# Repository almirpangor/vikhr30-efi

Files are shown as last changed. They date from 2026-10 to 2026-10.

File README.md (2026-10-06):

# Вихрь-30 EFI

Блок управления впрыском и зажиганием для лодочного мотора «Вихрь-30» на STM32F103C6T6 (Blue Pill):
программа настройки, прошивка, схема и печатная плата.

| Папка | Что внутри |
|---|---|
| `app/` | Программа настройки 2.0 (TypeScript, React, свой WebGL-движок). `app/desktop/` — оболочка настольного приложения (Electron). Сборка: `node build.mjs`, тесты ядра: `npm test`. |
| `firmware/` | Прошивка v0.9 (исправленная) и v0.8 (для отката), симулятор и тесты на хосте, готовые HEX/BIN в `firmware/release/`. Читать `firmware/README_RU.md`. |
| `pcb/` | Печатная плата rev A: генератор, Gerber и сверловка в `pcb/out/`, файл KiCad, сборочные рисунки, перечень. Читать `pcb/out/README_RU.md`. |
| `release/` | Собранная программа одним HTML-файлом (Chrome/Edge). Установщик для Windows — в разделе Releases. |

## Состояние

Проверено без железа: 24 автотеста ядра программы, 48 проверок прошивки на симуляторе, соответствие Gerber схеме по всем 63 цепям.

**Не проверено на железе:** прошивка v0.9 на настоящем контроллере, программа с настоящим COM-портом,
установщик на Windows, плата (не изготавливалась, файл KiCad в KiCad не открывался), схема из новых деталей.
Перед заказом платы — список «Сверить перед заказом» в `pcb/out/README_RU.md`.

Первые включения — на стенде, с предохранителем и ограничением тока, без топлива. Цепи катушек — до 400 В.

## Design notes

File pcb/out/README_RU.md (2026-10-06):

# Плата блока управления «VIKHR-30 EFI rev A» (2026-10)

> **Состояние:** плата спроектирована программно по схеме из программы, проверена собственными скриптами (см. `CHECK.txt`), но **не изготавливалась и не испытывалась**. Файл KiCad в KiCad не открывался, штатный DRC KiCad не выполнялся. Часть посадочных мест нарисована по памяти — **перед заказом пройдите раздел «Сверить перед заказом»**.

## Параметры для заказа
| Параметр | Значение |
|---|---|
| Размер | 148 × 100 мм, прямоугольник |
| Слои | 2 (F.Cu, B.Cu), FR-4, толщина 1,6 мм |
| Медь | 35 мкм (1 oz) — минимум; **рекомендуется 70 мкм (2 oz)** для силовой части (шина +12V_F2, цепи катушек) |
| Мин. дорожка / зазор | 0,4 / 0,3 мм (фактический минимальный зазор 0,36 мм) |
| Мин. отверстие / площадка переходного | 0,4 / 0,8 мм (силовые 0,6 / 1,2) |
| Отверстия | металлизированных 326 (0,4…1,5 мм), неметаллизированных 6 (⌀3,2) |
| Маска | зелёная, с двух сторон; переходные закрыты маской |
| Шелкография | белая, с двух сторон (снизу — только название и «ДО 400 В») |
| Финиш | HASL (лучше бессвинцовый) |
| Контроль | электроконтроль (E-test) — заказать обязательно |

## Как заказать
- **Резонит** (rezonit.ru, «Срочные прототипы» / калькулятор): загрузить `vikhr30-efi-gerber.zip`; указать 2 слоя, 148 × 100, 1,6 мм, медь 35 или 70 мкм, маска зелёная, маркировка с двух сторон, HASL.
- **JLCPCB**: загрузить тот же zip; слои и размер определятся сами; Outer Copper Weight 1 oz или 2 oz; Surface Finish HASL. Плата больше 100 × 100 — цена выше минимальной.
- В архиве: `F_Cu`, `B_Cu`, `F_Mask`, `B_Mask`, `F_Paste`, `F_Silkscreen`, `B_Silkscreen`, `Edge_Cuts` (Gerber RS-274X, мм, 4.6) и сверловка `PTH.drl`, `NPTH.drl` (Excellon, мм, десятичные координаты). Начало координат — левый нижний угол платы.
- После загрузки **посмотрите предпросмотр завода**: должны быть видны сплошная заливка с обеих сторон, два «острова» под Q1/Q2 с широким зазором, 4 крепёжных отверстия по углам.

## Файлы
`vikhr30-efi.kicad_pcb` (+ `vikhr30-efi.kicad_dru` — правила зазоров, включая 2,5 мм для COIL1−/COIL2−), `top.svg/png`, `bottom.svg/png` (вид снизу — зеркально), `assembly.svg/png` (сборочный с номиналами), `all-layers.svg/png`, `bom.csv`, `placement.csv` (SMD), `pads.csv` (координаты всех выводов), `CHECK.txt` (результаты проверок), `../netlist.txt`, `../DECISIONS.md`.
В KiCad: зоны записаны уже залитыми — **не перезаливать (клавиша B)**, пока не подключён файл правил `.kicad_dru`, иначе KiCad зальёт с зазором 0,45 мм и возле ВВ-цепей. 3D-моделей в файле нет (в 3D будет видна только плата).

## Порядок сборки
1. Осмотреть плату, прозвонить: BAT+ ↔ GND, +12V_F2 ↔ GND, К1− ↔ GND, К2− ↔ GND — замыканий быть не должно.
2. **SMD**: D6…D9, D11 (BAR43S), Q3…Q6 (AO3400A), U3 (L293DD — ключ у вывода 1, точка на шелке), L1, D2 (SM8S30A: фланец-теплоотвод — АНОД, паяется на большую площадку в полигоне GND; отформованный вывод — катод, на малую площадку +12V_PROT у двойной черты на шелке) либо выводной P6KE33A/1.5KE33A в запасные отверстия, Q1, Q2 (D2PAK — фланец прогревать мощным паяльником или феном).
3. **Низкие выводные**: резисторы, диоды D3…D5 (полоска — к квадратной площадке), D1 (полоска вверх, к квадратной площадке).
4. Керамические конденсаторы, Q9 (BC547 — плоской стороной к клеммам, как на шелке), гнёзда PBS под A1 и A2, разъёмы JST.
5. Электролиты (плюс — квадратная площадка и знак «+»), Q7, Q8 (TO-220 стоя, фланец — к двойной линии на шелке), клеммники.
6. Модуль A5 — на двух стойках М3, четыре провода (или штыри) к площадкам IN+, IN−, OUT+, OUT−.
7. Промыть флюс. Силовую часть (вокруг Q1, Q2 и клемм катушек, **включая обратную сторону**) покрыть лаком для печатных плат.

## Проверка мультиметром ДО установки Blue Pill, HC-06 и подключения нагрузок
(цепи и ожидаемые значения — на вкладках «Схема» и «3D-схема» программы: щелчок по цепи показывает, что должно быть на ней)
1. Без питания: сопротивление BAT+ ↔ GND и +12V_F2 ↔ GND — не короткое; К1−, К2−, INJ, HTR, REL ↔ GND — не короткое (ключи закрыты).
2. Вставить предохранитель F1 (2 А), F2 пока **не ставить**. Подать 12 В от источника с ограничением тока 0,3…0,5 А.
3. +12V_PROT (катод D1, контакт IN+ модуля A5): на ~0,4 В меньше входного.
4. **Выставить подстроечником A5 ровно 5,00 В** на OUT+ (цепь +5V_ECU) — до установки A1!
5. +5V_SENS на контакте «5V» разъёмов TPS, MAP, CKP: 5,0 В. Контакт «5V» гнезда A1 (JR3): 5,0 В; контакты 3V3 пока пустые.
6. Затворы Q1, Q2 (IGN1_GATE, IGN2_GATE): около 0 В (катушки выключены, пока нет контроллера). Затворы Q7, Q8, база Q9: 0 В.
7. Обесточить, установить Blue Pill **по надписям контактов** (VBAT/3V3 — справа), включить: +3V3 = 3,3 В на R7, R10, R16, R18, R20, R38; PA4/PA5 без термисторов ≈ 3,3 В; PA6 ≈ U бортсети / 5,7.
8. Только после этого — F2, нагрузки по одной через тесты программы (вкладка «Тесты»), катушки — последними.

## Высокое напряжение — обязательно прочитать
- На клеммах **K1−, K2−**, фланцах Q1, Q2 и полигонах под ними **с обеих сторон платы** в момент искры до **400 В**. Не касаться при работающем двигателе; измерять только осциллографом со щупом 1:10 на 600 В.
- На плате зазор от этих цепей до любой другой меди ≥ 2,55 мм. **Внутри самих деталей он меньше**: у D2PAK между обрезанным средним выводом (коллектор) и выводами затвора/эмиттера около 1 мм по воздуху, между контактами клеммника 2,58 мм. Поэтому — лак, чистота, сухой корпус.
- Плату ставить на стойки не ниже 5 мм над металлом корпуса (снизу открытая медь ВВ-цепей под маской и выводы клемм). Рядом топливо: корпус блока — закрытый, вне зоны паров бензина.

## Сверить перед заказом (посадочные места по памяти и допущения)
| Что | Что сверить |
|---|---|
| D2 SM8S30A (DO-218AB) | **полярность**: по даташиту Vishay «Polarity: heatsink is anode» — на плате большая площадка = GND (анод), малая = +12V_PROT (катод); в rev A до рецензии было наоборот (исправлено). Сверить по даташиту купленного диода и прозвонить диод мультиметром до пайки. Размеры: площадки 10,5 × 9,3 и 3,0 × 3,8, зазор 2,45, длина 15,95; если не совпало — ставить выводной TVS в запасные отверстия (шаг 22,86, ⌀1,4; катод — квадратная площадка, полоска к ней) |
| Q1, Q2 IRGS14C40L (TO-263) | фланец 10,8 × 9,4; выводы 1,5 × 4,0, шаг 5,08; от центра фланца до центра площадок выводов 9,45; цоколёвка 1-G, 2-C (фланец), 3-E |
| L1 CDRH125 | площадки 3,0 × 5,4, между центрами 10,0 |
| U3 L293DD (SO-20W) | шаг 1,27, между рядами 9,3 — стандарт; убедиться, что куплен именно широкий SO-20 (7,5 мм) |
| A5 LM2596 | габарит ≤ 45 × 23, положение крепёжных отверстий (30,4 × 16,4 по диагонали) — у вашего модуля может отличаться |
| Клеммники 5,08 | глубина корпуса и положение выводов (на плате: 4,0 мм от ряда выводов внутрь платы, 4,6 мм к кромке); подписи контактов у самой кромки |
| A1 Blue Pill | расстояние между рядами 15,24; порядок выводов по надписям; с какого торца USB (см. `DECISIONS.md`, п. 11) |
| A2 HC-06 | порядок выводов STATE-RXD-TXD-GND-VCC-EN; у 4-контактных плат порядок другой — тогда проводами |
| BAR43S, AO3400A, BC547C, SS441A | цоколёвки (как в примечаниях схемы) |
| Q7, Q8 IRLZ44N | работа при 3,3 В на затворе (нагрев Q8 на токе нагревателя) |
| Q7, Q8 фланцы | фланец TO-220 — сток (цепи INJ−, HEATER−): радиаторы Q7 и Q8 раздельные или через изолирующие прокладки; общий радиатор и касание корпуса недопустимы |
| Переполюсовка аккумулятора | D1 защищает только ветвь F1. В ветви F2 при обратной полярности ток пойдёт через внутренние диоды Q7, Q8 и D3, D4 (1N4007) — диоды сгорят раньше, чем F2 10 А. Не путать полярность; это свойство схемы, платой не исправляется |
| Земля эмиттера Q2 | от эмиттера Q2 к клемме GND ток идёт через 3 переходных 1,2/0,6 на нижний полигон (у Q1 — ещё и дорожка 3 мм). Для импульсов 8 А достаточно, но при сборке можно пропаять эти переходные проволокой |
| USB-кабель Blue Pill | у «классической» Blue Pill USB со стороны контактов PB12/GND — т. е. слева, над D2 и в сторону модуля A5 (высота 14 мм, от торца Blue Pill ≈ 30 мм): штекер проходит выше D2, но длинный штекер может упереться в A5 |
| Перечень | клеммников нужно 8 × 2 конт. + 1 × 4 конт. (в перечне программы 6); гнездо PBS-1×6 под HC-06 |

## Токи (IPC-2221, подробно — раздел E в `CHECK.txt`)
Шина +12V_F2 и перемычка BAT+ (2,5 мм на двух слоях): 7,7 А при перегреве 10 °C и 10,4 А при 20 °C на меди 35 мкм; 17 А на 70 мкм. Средний ток нагрузок 3…5 А — запас есть, но номинал F2 (10 А) длительно плата с медью 35 мкм держит на пределе: **заказывайте 70 мкм** либо не превышайте 7 А длительно.

## Что не проверено
DRC KiCad; совпадение посадочных мест с реальными деталями; тепловой режим Q1, Q2 (оценка 1…2 Вт на корпус на максимальных оборотах — полигона 2 × 1,4 см² может не хватить, предусмотрите пластину-теплоотвод); помехоустойчивость аналоговых входов (трассировка автоматическая); сама схема на железе.

## Пересборка
`pcb/make.sh` — заново извлекает список цепей из схемы, разводит плату, выпускает все файлы и выполняет проверки.

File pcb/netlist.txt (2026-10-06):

СПИСОК ЦЕПЕЙ ПЛАТЫ «VIKHR-30 EFI rev A» — получен программно из листов схемы (pcb/netlist.ts)

Элементов на плате: 94; цепей: 63; выводов в цепях: 258

ЭЛЕМЕНТЫ НА ПЛАТЕ (обозначение | номинал | корпус | вывод=цепь)
A1    Blue Pill STM32F103C6T6      BLUEPILL_2x20    JL1=(NC) JL2=PC13 JL3=(NC) JL4=(NC) JL5=PA0 JL6=PA1 JL7=(NC) JL8=(NC) JL9=PA4 JL10=PA5 JL11=PA6 JL12=PA7 JL13=PB0 JL14=PB1 JL15=PB10 JL16=PB11 JL17=(NC) JL18=V33 JL19=GND JL20=GND JR1=V33 JR2=GND JR3=V5 JR4=PB9 JR5=PB8 JR6=PB7 JR7=PB6 JR8=PB5 JR9=(NC) JR10=(NC) JR11=(NC) JR12=(NC) JR13=(NC) JR14=PA10 JR15=PA9 JR16=PA8 JR17=PB15 JR18=PB14 JR19=PB13 JR20=PB12
A2    HC-06                        HDR_1x6          1=PB14 2=PA9_A2 3=PA10_A2 4=GND 5=V5 6=(NC)
A5    LM2596S, 5,00 В              LM2596_MODULE    1=V12 2=GND 3=V5 4=GND
C1    470 мкФ × 25 В               CP_D8_P3.5       1=V12 2=GND
C2    47 мкФ × 63 В                CP_D6.3_P2.5     1=V5S 2=GND
C3    0,1 мкФ                      C_DISC_5.08      1=PA0 2=GND
C4    0,1 мкФ                      C_DISC_5.08      1=PA1 2=GND
C5    0,1 мкФ                      C_DISC_5.08      1=PA4 2=GND
C6    0,1 мкФ                      C_DISC_5.08      1=PA5 2=GND
C7    0,1 мкФ                      C_DISC_5.08      1=PA6 2=GND
C8    0,1 мкФ                      C_DISC_5.08      1=PA7 2=GND
C9    0,1 мкФ                      C_DISC_5.08      1=V5 2=GND
C13   1 нФ                         C_DISC_5.08      1=PB5 2=GND
C14   1 нФ                         C_DISC_5.08      1=PB13 2=GND
C15   1 нФ                         C_DISC_5.08      1=PB12 2=GND
C16   47 мкФ × 63 В                CP_D6.3_P2.5     1=V5 2=GND
C17   47 мкФ × 63 В                CP_D6.3_P2.5     1=V12 2=GND
D1    SR560                        DO-201AD_15.24   1=V12 2=N_D1_A
D2    SM8S30A                      DO-218AB         1=V12 2=GND
D3    1N4007                       DO-41_10.16      1=F2 2=INJ
D4    1N4007                       DO-41_10.16      1=F2 2=HEAT
D5    1N4007                       DO-41_10.16      1=F2 2=RELAY
D6    BAR43S                       SOT-23           1=GND 2=V33 3=PA0
D7    BAR43S                       SOT-23           1=GND 2=V33 3=PA1
D8    BAR43S                       SOT-23           1=GND 2=V33 3=PA6
D9    BAR43S                       SOT-23           1=GND 2=V33 3=PA7
D11   BAR43S                       SOT-23           1=GND 2=V33 3=PB5
L1    47 мкГн                      CDRH125          1=V5 2=V5S
Q1    IRGS14C40L                   TO-263-2         1=G1 2=COIL1 3=GND
Q2    IRGS14C40L                   TO-263-2         1=G2 2=COIL2 3=GND
Q3    AO3400A                      SOT-23           1=N_Q3_1 2=GND 3=N_Q3_3
Q4    AO3400A                      SOT-23           1=N_Q3_3 2=GND 3=G1
Q5    AO3400A                      SOT-23           1=N_Q5_1 2=GND 3=N_Q5_3
Q6    AO3400A                      SOT-23           1=N_Q5_3 2=GND 3=G2
Q7    IRLZ44N                      TO-220_V         1=N_Q7_1 2=INJ 3=GND
Q8    IRLZ44N                      TO-220_V         1=N_Q8_1 2=HEAT 3=GND
Q9    BC547C                       TO-92            1=RELAY 2=N_Q9_2 3=GND
R1    10 кОм                       R_AXIAL_10.16    1=TPS_SIG 2=N_R1_2
R2    20 кОм                       R_AXIAL_10.16    1=N_R1_2 2=GND
R3    1 кОм                        R_AXIAL_10.16    1=N_R1_2 2=PA0
R4    10 кОм                       R_AXIAL_10.16    1=MAP_SIG 2=N_R4_2
R5    20 кОм                       R_AXIAL_10.16    1=N_R4_2 2=GND
R6    1 кОм                        R_AXIAL_10.16    1=N_R4_2 2=PA1
R7    2,4 кОм                      R_AXIAL_10.16    1=V33 2=N_R7_2
R8    91 Ом                        R_AXIAL_10.16    1=N_R7_2 2=PA4_X4
R9    1 кОм                        R_AXIAL_10.16    1=PA4_X4 2=PA4
R10   2,4 кОм                      R_AXIAL_10.16    1=V33 2=N_R10_2
R11   91 Ом                        R_AXIAL_10.16    1=N_R10_2 2=PA5_X5
R12   1 кОм                        R_AXIAL_10.16    1=PA5_X5 2=PA5
R13   47 кОм                       R_AXIAL_10.16    1=V12 2=PA6
R14   10 кОм                       R_AXIAL_10.16    1=PA6 2=GND
R15   10 кОм                       R_AXIAL_10.16    1=PA7_X6 2=PA7
R16   4,7 кОм                      R_AXIAL_10.16    1=V33 2=PB5_X7
R17   1 кОм                        R_AXIAL_10.16    1=PB5_X7 2=PB5
R18   10 кОм                       R_AXIAL_10.16    1=V33 2=PB13_X8
R19   1 кОм                        R_AXIAL_10.16    1=PB13_X8 2=PB13
R20   10 кОм                       R_AXIAL_10.16    1=V33 2=PB12_X9
R21   1 кОм                        R_AXIAL_10.16    1=PB12_X9 2=PB12
R22   1 кОм                        R_AXIAL_10.16    1=PA9 2=PA9_A2
R23   1 кОм                        R_AXIAL_10.16    1=PA10 2=PA10_A2
R24   330 Ом                       R_AXIAL_10.16    1=PB0 2=N_Q3_1
R25   10 кОм                       R_AXIAL_10.16    1=N_Q3_1 2=GND
R26   1 кОм                        R_AXIAL_10.16    1=V5 2=N_Q3_3
R27   470 Ом                       R_AXIAL_10.16    1=V5 2=G1
R28   330 Ом                       R_AXIAL_10.16    1=PB1 2=N_Q5_1
R29   10 кОм                       R_AXIAL_10.16    1=N_Q5_1 2=GND
R30   1 кОм                        R_AXIAL_10.16    1=V5 2=N_Q5_3
R31   470 Ом                       R_AXIAL_10.16    1=V5 2=G2
R32   100 Ом                       R_AXIAL_10.16    1=PB10 2=N_Q7_1
R33   100 кОм                      R_AXIAL_10.16    1=N_Q7_1 2=GND
R34   100 Ом                       R_AXIAL_10.16    1=PB15 2=N_Q8_1
R35   100 кОм                      R_AXIAL_10.16    1=N_Q8_1 2=GND
R36   1 кОм                        R_AXIAL_10.16    1=PB11 2=N_Q9_2
R37   10 кОм                       R_AXIAL_10.16    1=N_Q9_2 2=GND
R38   10 кОм                       R_AXIAL_10.16    1=V33 2=PC13
U3    L293DD                       SO-20W           1=PA8 2=PB6 3=IAC_A1 4=GND 5=GND 6=GND 7=GND 8=IAC_A2 9=PB7 10=V12 11=PA8 12=PB8 13=IAC_B1 14=GND 15=GND 16=GND 17=GND 18=IAC_B2 19=PB9 20=V5
X1    Клеммник 2 конт.             TERM_5.08_2      1=BAT 2=GND
X2    JST XH 3 конт.               JST_XH_3         1=V5S 2=TPS_SIG 3=GND
X3    JST XH 3 конт.               JST_XH_3         1=V5S 2=MAP_SIG 3=GND
X4    JST XH 2 конт.               JST_XH_2         1=PA4_X4 2=GND
X5    JST XH 2 конт.               JST_XH_2         1=PA5_X5 2=GND
X6    JST XH 2 конт.               JST_XH_2         1=PA7_X6 2=GND
X7    JST XH 3 конт.               JST_XH_3         1=V5S 2=PB5_X7 3=GND
X8    JST XH 2 конт.               JST_XH_2         1=PB13_X8 2=GND
X9    JST XH 2 конт.               JST_XH_2         1=PB12_X9 2=GND
X10   Клеммник 2 конт.             TERM_5.08_2      1=F2 2=COIL1
X11   Клеммник 2 конт.             TERM_5.08_2      1=F2 2=COIL2
X12   Клеммник 2 конт.             TERM_5.08_2      1=F2 2=INJ
X13   Клеммник 2 конт.             TERM_5.08_2      1=F2 2=RELAY
X14   Клеммник 2 конт.             TERM_5.08_2      1=F2 2=HEAT
X15   JST XH 4 конт.               TERM_5.08_4      1=IAC_A1 2=IAC_A2 3=IAC_B1 4=IAC_B2
X16   JST XH 4 конт. (USB-UART A3) JST_XH_4         1=GND 2=PA9 3=PA10 4=(NC)
XF1   Клеммник 2 конт. к держателю F1 (2 А) TERM_5.08_2      1=BAT 2=N_D1_A
XF2   Клеммник 2 конт. к держателю F2 (10 А) TERM_5.08_2      1=BAT 2=F2

ЦЕПИ (имя | название | выводы)
BAT          BAT+        X1.1 XF1.1 XF2.1
COIL1        COIL1−      Q1.2 X10.2
COIL2        COIL2−      Q2.2 X11.2
F2           +12V_F2     D3.1 D4.1 D5.1 X10.1 X11.1 X12.1 X13.1 X14.1 XF2.2
G1           IGN1_GATE   Q1.1 Q4.3 R27.2
G2           IGN2_GATE   Q2.1 Q6.3 R31.2
GND          GND         A1.JL19 A1.JL20 A1.JR2 A2.4 A5.2 A5.4 C1.2 C2.2 C3.2 C4.2 C5.2 C6.2 C7.2 C8.2 C9.2 C13.2 C14.2 C15.2 C16.2 C17.2 D2.2 D6.1 D7.1 D8.1 D9.1 D11.1 Q1.3 Q2.3 Q3.2 Q4.2 Q5.2 Q6.2 Q7.3 Q8.3 Q9.3 R2.2 R5.2 R14.2 R25.2 R29.2 R33.2 R35.2 R37.2 U3.4 U3.5 U3.6 U3.7 U3.14 U3.15 U3.16 U3.17 X1.2 X2.3 X3.3 X4.2 X5.2 X6.2 X7.3 X8.2 X9.2 X16.1
HEAT         HEATER−     D4.2 Q8.2 X14.2
IAC_A1       IAC_A1      U3.3 X15.1
IAC_A2       IAC_A2      U3.8 X15.2
IAC_B1       IAC_B1      U3.13 X15.3
IAC_B2       IAC_B2      U3.18 X15.4
INJ          INJ−        D3.2 Q7.2 X12.2
MAP_SIG      MAP         R4.1 X3.2
N_D1_A       N_D1_A      D1.2 XF1.2
N_Q3_1       N_Q3_1      Q3.1 R24.2 R25.1
N_Q3_3       N_Q3_3      Q3.3 Q4.1 R26.2
N_Q5_1       N_Q5_1      Q5.1 R28.2 R29.1
N_Q5_3       N_Q5_3      Q5.3 Q6.1 R30.2
N_Q7_1       N_Q7_1      Q7.1 R32.2 R33.1
N_Q8_1       N_Q8_1      Q8.1 R34.2 R35.1
N_Q9_2       N_Q9_2      Q9.2 R36.2 R37.1
N_R1_2       N_R1_2      R1.2 R2.1 R3.1
N_R4_2       N_R4_2      R4.2 R5.1 R6.1
N_R7_2       N_R7_2      R7.2 R8.1
N_R10_2      N_R10_2     R10.2 R11.1
PA0          PA0         A1.JL5 C3.1 D6.3 R3.2
PA1          PA1         A1.JL6 C4.1 D7.3 R6.2
PA4          PA4         A1.JL9 C5.1 R9.2
PA4_X4       PA4_X4      R8.2 R9.1 X4.1
PA5          PA5         A1.JL10 C6.1 R12.2
PA5_X5       PA5_X5      R11.2 R12.1 X5.1
PA6          PA6         A1.JL11 C7.1 D8.3 R13.2 R14.1
PA7          PA7         A1.JL12 C8.1 D9.3 R15.2
PA7_X6       PA7_X6      R15.1 X6.1
PA8          PA8         A1.JR16 U3.1 U3.11
PA9          PA9         A1.JR15 R22.1 X16.2
PA9_A2       PA9_A2      A2.2 R22.2
PA10         PA10        A1.JR14 R23.1 X16.3
PA10_A2      PA10_A2     A2.3 R23.2
PB0          PB0         A1.JL13 R24.1
PB1          PB1         A1.JL14 R28.1
PB5          PB5         A1.JR8 C13.1 D11.3 R17.2
PB5_X7       PB5_X7      R16.2 R17.1 X7.2
PB6          PB6         A1.JR7 U3.2
PB7          PB7         A1.JR6 U3.9
PB8          PB8         A1.JR5 U3.12
PB9          PB9         A1.JR4 U3.19
PB10         PB10        A1.JL15 R32.1
PB11         PB11        A1.JL16 R36.1
PB12         PB12        A1.JR20 C15.1 R21.2
PB12_X9      PB12_X9     R20.2 R21.1 X9.1
PB13         PB13        A1.JR19 C14.1 R19.2
PB13_X8      PB13_X8     R18.2 R19.1 X8.1
PB14         PB14        A1.JR18 A2.1
PB15         PB15        A1.JR17 R34.1
PC13         PC13        A1.JL2 R38.2
RELAY        RELAY−      D5.2 Q9.1 X13.2
TPS_SIG      TPS         R1.1 X2.2
V5           +5V_ECU     A1.JR3 A2.5 A5.3 C9.1 C16.1 L1.1 R26.1 R27.1 R30.1 R31.1 U3.20
V5S          +5V_SENS    C2.1 L1.2 X2.1 X3.1 X7.1
V12          +12V_PROT   A5.1 C1.1 C17.1 D1.1 D2.1 R13.1 U3.10
V33          +3V3        A1.JL18 A1.JR1 D6.2 D7.2 D8.2 D9.2 D11.2 R7.1 R10.1 R16.1 R18.1 R20.1 R38.1

ВНЕ ПЛАТЫ (подключаются через разъёмы)
GB1   12 В                           1=BAT 2=GND
F1    2 А                            1=BAT 2=N_D1_A
F2    10 А                           1=BAT 2=F2
A3    USB-UART PL2303HX              GND=GND TXD=PA10 RXD=PA9 +5V=(NC) 3V3=(NC)
A4    ST-Link V2                     GND=GND SWDIO=SWDIO SWCLK=SWCLK 3.3V=(NC)
RP1   Датчик дросселя                1=V5S 2=GND 3=TPS_SIG
B2    MPX4115AP                      2:GND=GND 3:Vs=V5S 1:Вых.=MAP_SIG
RT1   NTC 10 кОм B3950               1=PA4_X4 2=GND
RT2   NTC 10 кОм B3950               1=PA5_X5 2=GND
B3    Лямбда-зонд                    1/Масса=GND 2/1=F2 1/Сигн.=PA7_X6 2/2=HEAT
B1    SS441A                         2:GND=GND 1:+=V5S 3:Вых.=PB5_X7
S1    Перемычка SERVICE              1=PB13_X8 2=GND
S2    Чека STOP                      1=PB12_X9 2=GND
M1    Бензонасос                     1=N_K1_1_2 2=GND
T1    Катушка зажигания 1            1=F2 2=COIL1
T2    Катушка зажигания 2            1=F2 2=COIL2
Y1    Форсунка Bosch 0 280 158 117   1=F2 2=INJ
K1    Реле 12 В 30 А                 1=F2 2=RELAY 1/1=F2 1/2=N_K1_1_2
M2    Шаговый РХХ                    1/1=IAC_A1 1/2=IAC_A2 2/1=IAC_B1 2/2=IAC_B2

ПРЕОБРАЗОВАНИЯ «СХЕМА → ПЛАТА»
 - F1: держатель ножевого предохранителя вне платы; на плате клеммник XF1: 1 → BAT, 2 → N_D1_A.
 - F2: держатель ножевого предохранителя вне платы; на плате клеммник XF2: 1 → BAT, 2 → F2.
 - A3 (USB-UART) на плату не ставится: разъём X16 JST XH 4 конт.: 1 GND, 2 → RXD адаптера (PA9), 3 ← TXD адаптера (PA10), 4 не подключён (3V3 адаптера).
 - A2 (HC-06): гнездо 1×6, порядок как на модуле: 1 STATE, 2 RXD, 3 TXD, 4 GND, 5 VCC, 6 EN (не подключён).
 - A1: контакты SWD (S1…S4) находятся на торце самой Blue Pill и на плату не выводятся; A4 (ST-Link) подключается прямо к ним. Цепи SWDIO/SWCLK на плате отсутствуют.

ЗАМЕЧАНИЯ ПРИ ИЗВЛЕЧЕНИИ
 - Участок с цветом цепи «PA9» без метки на листе mcu (A2.RXD, R22.2) — отдельная цепь PA9_A2
 - Участок с цветом цепи «PA10» без метки на листе mcu (A2.TXD, R23.2) — отдельная цепь PA10_A2
 - Участок с цветом цепи «PA4» без метки на листе sensors (X4.1:Сигн., RT1.1, R8.2, R9.1) — отдельная цепь PA4_X4
 - Участок с цветом цепи «PA5» без метки на листе sensors (X5.1:Сигн., RT2.1, R11.2, R12.1) — отдельная цепь PA5_X5
 - Участок с цветом цепи «PA7» без метки на листе sensors (B3.1.Сигн., X6.1:Сигн., R15.1) — отдельная цепь PA7_X6
 - Участок с цветом цепи «PB5» без метки на листе sensors (B1.3:Вых., X7.2:Вых., R16.2, R17.1) — отдельная цепь PB5_X7
 - Участок с цветом цепи «PB13» без метки на листе sensors (X8.1:Вход, S1.1, R18.2, R19.1) — отдельная цепь PB13_X8
 - Участок с цветом цепи «PB12» без метки на листе sensors (X9.1:Вход, S2.1, R20.2, R21.1) — отдельная цепь PB12_X9
 - Участок с цветом цепи «IAC_OUT» без метки на листе iac (U3.3:OUT1, X15.1:A1, M2.1.1) — отдельная цепь IAC_A1
 - Участок с цветом цепи «IAC_OUT» без метки на листе iac (U3.8:OUT2, X15.2:A2, M2.1.2) — отдельная цепь IAC_A2
 - Участок с цветом цепи «IAC_OUT» без метки на листе iac (U3.13:OUT3, X15.3:B1, M2.2.1) — отдельная цепь IAC_B1
 - Участок с цветом цепи «IAC_OUT» без метки на листе iac (U3.18:OUT4, X15.4:B2, M2.2.2) — отдельная цепь IAC_B2

ПРОВЕРКА
 Замечаний нет: каждый вывод каждого элемента на плате имеет цепь или явно свободен; цепей с одним выводом нет; все элементы SCHEME_PARTS найдены.

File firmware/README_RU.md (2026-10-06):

# Прошивка блока впрыска «Вихрь-30», версия 0.9.0-C6-BT-DIAG

STM32F103C6T6A, bare-metal C, без HAL и библиотек. Это исправленная v0.8:
протокол и страница калибровок те же, программа настройки работает без
переделки.

## ВАЖНО: чего эта прошивка НЕ прошла

**Образ v0.9 ни разу не запускался на настоящем контроллере — ни автором
исправлений, ни кем-либо ещё.** Он собран clang 18 + ld.lld (v0.8 собиралась
arm-none-eabi-gcc). Проверено всё, что можно проверить без железа: логика —
на симуляторе на ПК (48 проверок, см. `tests/RESULTS.txt`), образ —
статически (векторы, размеры, HEX = BIN, дизассемблер). Первое включение —
только на стенде без катушек, форсунки и насоса, по порядку из раздела
«Первая проверка».

## Что было неверно в v0.8 и что сделано

Номера строк: «v0.8» — `tests/v0.8/main.c`, «v0.9» — `src/main.c`.

### 1. Таймер TIM2 — 16-разрядный, а код считал его 32-разрядным (критично)

v0.8, строка 1091: `TIM2->ARR=0xFFFFFFFF`. В STM32F103 счётчик TIM2 считает
только до 65535, то есть при шаге 1 мкс обнуляется каждые 65,5 мс. Отсюда:

- событие «выключить катушку/форсунку», назначенное на время после
  обнуления, никогда не выполнялось: проверка в строке 676 сравнивала
  число больше 65535 со счётчиком, который до него не доходит. Запись
  оставалась в очереди навсегда, очередь из 12 мест забивалась;
- зуб, пришедший сразу после обнуления, отбрасывался (строка 725), счёт
  зубьев сбивался;
- проверка «двигатель остановился» (строка 1121) срабатывала ложно почти
  после каждого обнуления, а настоящую остановку на 250 мс измерить не могла.

На симуляторе v0.8 при 3000 об/мин за 3,2 с: из 320 искр выдано 57, из 320
впрысков 187, катушка оставалась под током до 14,7 мс (норма 1,6 мс),
форсунка открыта до 12,5 мс (норма 2,1 мс). При 300–600 об/мин искр не было
вообще.

Сделано в v0.9:

- `micros()` (строка 736): 32-разрядное время в микросекундах. Старшую часть
  считает прерывание переполнения TIM2 (строка 810). Чтение защищено от
  гонки: если переполнение уже случилось, но ещё не посчитано, это видно по
  флагу UIF;
- новый планировщик (строки 744–816): на каждое действие своя ячейка
  (включить/выключить катушку 1 и 2, закрыть форсунку), время хранится в
  32 битах. Событие в прошлом выполняется сразу, далёкое — через
  промежуточные пробуждения. Очередь не может переполниться;
- включение выхода и назначение его выключения делаются в одном прерывании,
  поэтому катушка и форсунка выключаются таймером, даже если основной цикл
  занят или двигатель внезапно встал.

### 2. Обнаружение остановки читало время раньше, чем метку зуба

v0.8, строки 1117 и 1120: время бралось в начале цикла, метка последнего зуба
— позже. Если между ними приходил зуб, разность получалась «отрицательной»
(огромной), и блок решал, что двигатель стоит: сбрасывал синхронизацию и
выключал выходы. Контрольный опыт на симуляторе показал, что из-за этого
v0.8 не работала бы даже с 32-разрядным таймером (12 искр из 320).
Побочное следствие: блокировка SERVICE/обороты пропускала команды `SET`,
`SAVE`, `TEST` на вращающемся двигателе.

v0.9, строки 1331–1344: время, метка и сброс состояния — в одной защищённой
секции.

### 3. Период зуба после сбоя или помехи

- v0.8 не сбрасывала измеренный период зуба при остановке. После обрыва
  сигнала на 3000 об/мин и повторной прокрутки каждый зуб принимался за
  пропуск венца: на симуляторе 348 искр вместо 30 за 3 с, катушка под током
  до 18 мс.
- Два импульса помехи перед началом прокрутки давали то же самое, причём
  навсегда: блок показывал 12000 об/мин и отсекал зажигание и топливо.

v0.9: период сбрасывается при остановке (строка 1340) и при паузе больше
100 мс (строка 889); «пропуск» сразу после пропуска считается ошибкой
измерения, период измеряется заново (строка 899).

- Целочисленный фильтр периода в v0.8 (строка 731) после торможения
  застревал до 7 мкс ниже истинного значения: при 6000 об/мин это 2,5 % и
  искра примерно на 3,6° раньше заданной. В v0.9 фильтр считает в 1/8 мкс
  (строка 910), ошибка не больше 0,5 мкс.

### 4. Передача по UART останавливала основной цикл

v0.8 ждала отправки каждого байта (строки 382–386). Телеметрия в два порта
занимала 18–20 мс десять раз в секунду, ответ `GET MAPS` — 115 мс.
Что показал симулятор:

- залп из 234 команд `SET` при простое v0.8 **выдерживает** (все 234
  применены): за 18 мс приходит около 212 байт, буфер 256. Запас 43 байта;
- если залп идёт сразу после `GET MAPS`, v0.8 теряет 64 команды из 234;
- несколько длинных запросов подряд останавливали цикл v0.8 на 770 мс при
  сторожевом таймере 1 с.

v0.9: передача по прерыванию через кольцевые буферы 2048 байт на порт
(строки 422–471), приём 512 байт. Телеметрия отправляется только если строка
помещается целиком (строка 1358), иначе пропускается. Ответы на команды не
теряются: если буфер полон, блок ждёт освобождения места. За один проход
цикла выполняется одна команда (строка 1265). Результат: все 234 команды
применены в обоих случаях, цикл не задерживается дольше 1,5 мс; при четырёх
`GET MAPS` подряд — до 106 мс.

### 5. Прочее

- **Запись Flash и тестовый импульс.** `TEST INJECTOR` и сразу `SAVE` в v0.8
  держали форсунку открытой 68,5 мс: запись Flash запрещает прерывания
  примерно на 43 мс. v0.9 перед записью обрывает тест (строки 1242–1246).
- **Таймауты ожидания** в v0.8 никогда не срабатывали (проверялся счётчик
  после переполнения): при неисправном PLL, АЦП или Flash блок считал, что
  всё в порядке. v0.9: макрос `WAIT_WHILE` (строка 43).
- **Сторожевой таймер.** v0.8 записывала делитель до запуска IWDG. По
  документации (RM0008) значения переносятся только при работающем LSI,
  а он включается запуском; v0.8 работала за счёт несработавшего таймаута.
  v0.9 запускает IWDG первым (строка 388). На железе это не проверено.
- **Флаги ошибок** меняются и основным циклом, и прерыванием зуба; v0.9
  делает это в защищённой секции (строка 213).
- **Сброс флагов TIM2**: `SR &= ~флаг` в v0.8 мог стереть соседний флаг;
  v0.9 пишет `SR = ~флаг`.
- **Приоритеты.** TIM2 и вход венца теперь одного приоритета (не прерывают
  друг друга, это убирает гонки в планировщике). SysTick и UART ниже.
- **Переполнение приёмника UART** (флаг ORE) теперь сбрасывается; в v0.8 в
  редком случае прерывание могло зациклиться.
- **Аварийный выключатель и РХХ.** v0.8 при замкнутом PB12 на каждом проходе
  цикла обесточивала обмотки РХХ, хотя сама же задавала ему ход «закрыть».
  v0.9 останавливает тест только если он идёт (строка 1348).

## Что не менялось

- Структура калибровок и адрес 0x08007C00. Проверено: образ после `SAVE` у
  v0.8 и v0.9 совпадает побайтно, каждая версия читает калибровки другой.
- Команды, ответы, состав и порядок полей строки `T,…`. Строка `GET INFO`
  по-прежнему содержит `DRV8843` (чтобы не менять протокол).
- Карты, поправки, расчёт топлива и УОЗ, алгоритм ограничителя оборотов.
- Драйвер РХХ L293D: правки не понадобились. PC13 настроен входом с
  подтяжкой вверх, код читает «1» как «аварии нет».

Мелкие видимые отличия: бит 0 `fault_flags` (переполнение очереди) больше не
выставляется; бит 6 (потеря синхронизации) выставляется также при сбое счёта
зубьев; при `TEST …` + `SAVE` строка `TEST,DONE,…` приходит перед `OK,SAVED`.

## Новая команда GET CRC

Запрос `GET CRC`, ответ одной строкой: `CRC,<fuel>,<ign>,<params>` — три
десятичных числа 0…65535. Работает всегда (блокировка не нужна).

Алгоритм — CRC-16/CCITT-FALSE: полином 0x1021, начальное значение 0xFFFF, без
отражения, без финального XOR, старший бит первым. Контроль: строка
`123456789` даёт 0x29B1.

| Поле | Данные | Байт |
|---|---|---|
| fuel | карта топлива из ОЗУ: 9 строк (нагрузка) × 13 столбцов (обороты), по строкам, как `F,0 … F,8`; каждое значение uint16, младший байт первым | 234 |
| ign | карта УОЗ, тот же порядок, как `I,0 … I,8`; int16, младший байт первым | 234 |
| params | блок параметров, см. ниже | 32 |

Блок параметров по порядку (младший байт первым): `trigger_trim_tenths`
int16, `dwell_us`, `injector_deadtime_us`, `tps_min_raw`, `tps_max_raw`,
`fuel_scale_permille`, `rev_limit_soft`, `rev_limit_hard`, `iac_max_steps`,
`iac_crank_steps`, `iac_hot_steps`, `iac_target_rpm` — все uint16;
`iac_direction` int8 (1 или 0xFF для −1); `o2_heater_duty_pct` uint8;
`o2_mode` uint8; один байт 0x00; `wideband_lambda_min_milli` uint16;
`wideband_lambda_max_milli` uint16. `fixed_ign_tenths` в CRC не входит.

CRC считается по тому, что сейчас в ОЗУ блока (после `SET`, до `SAVE`).
Для заводских калибровок параметров ответ содержит `…,22772`.

## Как прошить (ST-Link)

1. Сохраните карты программой настройки в файл. Дополнительно можно снять
   копию страницы: `st-flash read cal_backup.bin 0x08007C00 0x400`.
2. Снимите питание с катушек, форсунки и насоса.
3. Запишите `release/vikhr30_ecu_v0.9.hex`:
   - STM32CubeProgrammer или ST-LINK Utility: Open file → Program & Verify.
     **Не включайте Full chip erase.**
   - или `st-flash --format ihex write release/vikhr30_ecu_v0.9.hex`.
4. Образ занимает 0x08000000…0x08004647. Обычная запись стирает только эти
   страницы, калибровки на 0x08007C00 остаются. **Full chip erase стирает и
   калибровки** — после него блок загрузится с заводскими картами
   (`BOOT,…,DEFAULTS`).
5. Контрольные суммы файлов — в `release/SHA256SUMS.txt`.

Откат на v0.8: так же запишите `release/v0.8/vikhr30_ecu_v0.8_bt_diag.hex`.
Калибровки сохраняются, формат общий.

## Первая проверка на стенде (без нагрузок)

Катушки, форсунка, насос и РХХ отключены. Питание — от источника с
ограничением тока. Осциллограф на PB0 (катушка 1), PB1 (катушка 2), PB10
(форсунка), второй канал — сигнал венца на PB5.

1. **Загрузка.** В терминале 115200 8N1 должны прийти `BOOTSTAGE,UART_READY,
   HSI_PLL64`, `BOOTSTAGE,HW_READY`, `BOOT,VIKHR30_STM32,0.9.0-C6-BT-DIAG,FLASH`
   (или `DEFAULTS`), затем строки `T,…` 10 раз в секунду. 24-е число после
   буквы `T` (время работы, мс) должно расти на 100 за строку. Если загрузка повторяется раз в
   секунду — срабатывает сторожевой таймер, дальше не идти.
2. **Покой.** PB0, PB1, PB10 — постоянный ноль. PB11 (насос) — «1» первые 2 с.
3. **Шкала времени.** Подайте на PB5 меандр 660 Гц с генератора (3,3 В).
   Блок должен показать около 1100 об/мин (±3 %: тактирование от внутреннего
   генератора). Синхронизации и импульсов на выходах быть не должно.
4. **Прокрутка венца** дрелью, 300–1500 об/мин. Ожидается:
   - PB0 и PB1: по одному импульсу за оборот, сдвиг между ними пол-оборота,
     ширина от 1,6 мс (при 13,8 В на входе измерения напряжения) до 2,4 мс
     (вход напряжения не подключён);
   - PB10: два импульса за оборот, 2–4 мс. При закрытом дросселе (или
     неподключённом датчике) выше 1800 об/мин впрыск отключается — это
     штатная отсечка на принудительном холостом ходу;
   - спад PB0 — через 165° после первого зуба за пропуском (ниже 450 об/мин
     УОЗ 5°), то есть через 16,5 зуба.
5. **Главная проверка исправления таймера.** Крутите не меньше минуты и
   поставьте запуск осциллографа по длительности импульса: PB0/PB1 шире 3 мс,
   PB10 шире 12 мс. Запуск не должен сработать ни разу. Пропусков импульсов
   и потери `sync` в телеметрии (12-е число после `T`) быть не должно.
6. **Остановка.** Резко остановите венец: все три выхода в нуле, через
   0,25 с обороты 0, `sync` 0, в `fault_flags` появляется 64.
7. **Команды.** С перемычкой SERVICE: `TEST COIL1` (импульс 1 мс на PB0),
   `TEST COIL2`, `TEST INJECTOR` (3 мс на PB10), `GET MAPS`, `GET CRC`. На
   вращающемся венце `SET`, `SAVE`, `TEST` должны отвечать `ERR,service_lock`.
8. Только после этого подключайте нагрузки: сначала катушки с разрядником,
   потом форсунку и насос.

## Сборка и тесты

- `./build.sh` — clang → ld.lld → ELF, BIN, HEX, карта, листинг и проверка
  образа (`release/vikhr30_ecu_v0.9.verify.txt`).
- `tests/run.sh` — собирает симулятор и прогоняет все проверки (около 4 мин),
  итог в `tests/RESULTS.txt`. `tests/run.sh --quick` — сокращённо.
- `build_arm_gcc.cmd` — сборка gcc для Windows, не проверялась.

Симулятор (`tests/host/sim.c`) компилирует тот же `src/main.c` и неизменённый
`tests/v0.8/main.c` на ПК с подменой регистров. Каждое обращение прошивки к
памяти продвигает модельное время; моделируются 16-разрядный TIM2 с
прерываниями сравнения и переполнения, приоритеты и запрет прерываний, венец
36-1, UART 115200, АЦП, Flash, сторожевой таймер.

## Что не проверено и известные ограничения

- Работа образа на реальном STM32F103C6T6A (и на клонах).
- Точное время выполнения кода: симулятор считает время по числу обращений к
  памяти (100 нс на обращение), а не по тактам. Проверены также 50, 300 нс и
  случайный разброс.
- Модели периферии написаны по документации тем же автором, что и
  исправления; ошибка в понимании документации может быть общей.
- Порядок запуска сторожевого таймера, поведение при отказе PLL/АЦП/Flash.
- Помехи, реальная форма сигнала датчика, неравномерность вращения при
  прокрутке стартёром.
- Во время `SAVE` прерывания запрещены около 43 мс (как в v0.8). Двигатель
  при этом должен стоять — это обеспечивает блокировка.
- Частота задаётся внутренним генератором (±1…2,5 %): обороты в телеметрии
  имеют ту же погрешность; на угол искры это не влияет.

Ограничения алгоритма, унаследованные от v0.8 (не менялись, решать вам):

1. **Момент искры считается один раз за оборот**, от опорного зуба, на 130–
   170° вперёд. При постоянных оборотах ошибка меньше 0,6°, но при резком
   изменении оборотов она большая: на симуляторе до 31° запаздывания при
   разгоне 600→6000 за 1,5 с, до 48° при 300→1100 за 0,6 с, до 14° опережения
   при торможении. При прокрутке стартёром (неравномерное вращение) это может
   быть существенно. Лечится пересчётом момента искры на каждом зубе.
2. **Положение пропуска венца не проверяется.** Один потерянный импульс
   датчика принимается за пропуск, и следующий такт выдаётся не в том угле
   (на симуляторе 13 искр из 82 с ошибкой больше 2° при 7 потерянных и 12
   лишних импульсах). Катушка и форсунка при этом не «залипают».
3. **Мягкий ограничитель** (6800) отсекает каждый второй такт, а тактов два
   на оборот — получается, что всегда отключён один и тот же цилиндр вместе с
   его порцией топлива. Форсунка одна на оба цилиндра, значит второй цилиндр
   на 6800+ об/мин получает примерно половину топлива. Для двухтактного
   мотора обеднение на высоких оборотах опасно; стоит пересмотреть до
   выхода на эти обороты.
4. После старта первые 1–2 искры могут запаздывать (до 35°), пока не
   установился фильтр периода зуба.

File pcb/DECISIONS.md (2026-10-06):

# Решения, принятые при проектировании платы «VIKHR-30 EFI rev A»

Источник соединений — листы схемы программы (`src/pages/scheme2d/sheets.ts`); список цепей извлекается скриптом `netlist.ts` → `netlist.json`, `netlist.txt`.

## Схема → плата
1. **Внешние устройства** (аккумулятор, датчики, катушки, форсунка, реле K1 и насос, лямбда-зонд, РХХ, ST-Link, USB-UART) на плате не стоят — вместо них разъёмы X1…X16, как на схеме.
2. **F1, F2** — держатели ножевых предохранителей вне платы (в перечне они «с держателем»). На плате клеммники **XF1** (BAT+ → F1 → анод D1) и **XF2** (BAT+ → F2 → шина +12V_F2). Без предохранителя (или перемычки) соответствующая ветвь обесточена.
3. **A3 (USB-UART)** — разъём **X16** JST XH 4 конт.: 1 GND, 2 RX адаптера (PA9), 3 TX адаптера (PA10), 4 не подключён. Как и на схеме, X16 подключён к PA9/PA10 напрямую (до резисторов R22, R23), HC-06 — после них. Одновременно A2 и A3 не подключать.
4. **A2 (HC-06)** — гнездо 1×6, шаг 2,54, порядок как на модуле: STATE, RXD, TXD, GND, VCC, EN (EN свободен). На листе схемы сказано «JST XH» — по заданию заказчика принято гнездо 1×6. Модуль ставить вертикально или так, чтобы он свисал наружу за левый край; у гнезда на обоих слоях нет заливки (зона 8,5 × 19 мм).
5. **A4 (ST-Link)** подключается к штырям SWD на торце самой Blue Pill; цепей SWDIO/SWCLK на плате нет.
6. **X15 (РХХ)** — на схеме и в перечне JST XH 4 конт., в задании заказчика — винтовой клеммник 4 провода. Принят клеммник 5,08 × 4 (ток до 0,6 А — подходит и то и другое).
7. **Цвет провода ≠ цепь.** На листах участок до защитного резистора покрашен цветом цепи контроллера (например, обе стороны R22 — «PA9»). Цепи объединяются только по меткам (флажки, знаки питания, масса); участок без метки считается отдельной цепью (PA4_X4, PB5_X7, PA9_A2 …). Иначе резисторы R9, R12, R15, R17, R19, R21, R22, R23 оказались бы закорочены. Полный список — в `netlist.txt`.
8. Метка **IAC_IN** на схеме общая для четырёх разных проводов (PB6…PB9), **IAC_OUT** — для четырёх выходов: разделены по тексту метки и по контакту разъёма.
9. **BAR43S** (D6…D9, D11): на схеме два диода; вывод 1 — к GND, 2 — к +3V3, 3 — к сигналу (как в примечании листа «Датчики»).

## Конструкция
10. **Размер 148 × 100 мм.** В 100 × 100 не уложиться без ущерба зазорам: ряд силовых клемм — 20 контактов × 5,08 мм, модуль LM2596 45 × 23, Blue Pill 53 × 23.
11. **Blue Pill** стоит в центре, ряды вдоль длинной стороны, контакт 1 (VBAT / 3V3) — справа. **Какой торец с micro-USB — неоднозначно:** в описании программы USB со стороны контакта 1, у распространённой «классической» Blue Pill — со стороны контактов 20 (PB12 / GND). Электрически это не важно: плату ставить **по надписям контактов** (все 40 подписаны на шелке). Высоких деталей нет в 20 мм от обоих торцов — кабель USB и провода SWD проходят с любой стороны (они на высоте гнёзд, 8,5 мм).
12. Под платой Blue Pill нет деталей выше 2 мм: только край трёх корпусов SOT-23 (D7, D8, D9; 1,1 мм) под выступающим краем. Между гнёздами — только дорожки.
13. **A5 (LM2596)**: место 45 × 23 мм, 4 площадки ⌀3,2 с отверстием 1,5 (IN+, IN−, OUT+, OUT−) под провода или штыри, два отверстия М3 (30,4 × 16,4 по диагонали) под стойки. Расположение отверстий у модулей разных производителей разное — сверить; проще соединить проводами. Под модулем деталей нет.
14. **D2 (SM8S30A, DO-218AB)** — посадочное место по памяти. **Исправлено при независимой рецензии:** у SM8S фланец-теплоотвод — анод («heatsink is anode»), поэтому большая площадка подключена к GND, малая (катод) — к +12V_PROT; раньше было наоборот — TVS оказался бы включён в прямом направлении и закоротил бы +12V_PROT. Подстраховка: рядом с SMD-площадками есть два отверстия ⌀1,4 с шагом 22,86 мм под выводной P6KE33A / 1.5KE33A (замена из перечня).
15. **Клеммники** — ряд вдоль нижней кромки, ввод проводов наружу; порядок слева направо: XF1, XF2, X1, X10, X11, X12, X14, X13, X15. X1.GND стоит рядом с клеммой катушки 1 — путь силовой земли короткий. X11 отодвинут от X10, чтобы между ВВ-полигонами было 5,8 мм.
16. **IGBT Q1, Q2 (D2PAK)**: фланец-коллектор к клеммам; полигон 12 × 11,9 мм на обоих слоях, 7 переходных 1,2/0,6 + 6 переходных 0,8/0,4 под фланцем; шейка 2,5 мм × 2 слоя к клемме «К−». Площадки выводов укорочены со стороны фланца: зазор фланец–выводы 2,75 мм (в типовом посадочном месте 2,15). Место для общей пластины-теплоотвода над Q1/Q2 свободно.
17. **Силовая земля**: эмиттер Q1 — дорожкой 3 мм прямо к X1.GND, эмиттеры Q1 и Q2 — группами переходных 1,2/0,6 на сплошной полигон нижнего слоя; истоки Q7, Q8, эмиттер Q9, X1.GND, A5 — без термобарьеров. Вся силовая часть — у нижней кромки, аналоговые входы — у верхней, ток нагрузок под аналоговой частью не течёт.
18. **+12V_F2** — шина 2,5 мм вдоль нижней кромки на обоих слоях (под корпусами клемм), отводы к клеммам на обоих слоях.
19. **Заливка GND** — на обоих слоях (настоящий полигон, зазор 0,45 мм, до ВВ 2,65 мм, термобарьеры 0,4/0,6 мм, островки удалены, перемычки уже 0,3 мм убраны). Верхняя заливка разбита дорожками на области; каждая соединена с нижней через выводные площадки или переходные (проверено).
20. **Переходные закрыты маской.** Шелк: латиница; кириллицей — только «ДО 400 В» и надпись внутри контура Blue Pill (собственный штриховой шрифт).
21. Q7, Q8 (TO-220) стоят вертикально фланцем к центру платы; за фланцем 15 мм без высоких деталей — место под радиатор.

## Замечания к схеме (плата сделана по схеме, не исправлялось)
- IRLZ44N управляется напрямую 3,3 В с вывода контроллера: при таком напряжении затвора сопротивление канала не нормировано (в даташите — от 4 В). Для форсунки 1 А достаточно; ток нагревателя лямбды проверить на нагрев Q8.
- В перечне 6 клеммников на 2 контакта, плате нужно 8 двухконтактных и один четырёхконтактный (или 10 двухконтактных); гнезда PBS-1×6 под HC-06 в перечне нет.

## Независимая рецензия (2026-10-04)
- Список цепей сверен с листами схемы, описанием блоков и прошивкой узел за узлом — расхождений нет; решение п. 7 (цепи только по меткам) не дало ни ложных объединений, ни разрывов.
- Blue Pill: порядок контактов и взаимное положение рядов соответствуют реальной плате (посадка не зеркальна). В `SCHEMATICS_RU.md` сказано «нумерация от micro-USB» — у классической Blue Pill VBAT/3V3 находятся у разъёма SWD, т. е. нумерация JL/JR на деле идёт от SWD; на плату это не влияет (ставить по надписям).
- Найдена и исправлена одна ошибка: полярность D2 (см. п. 14). Остальные замечания вынесены в «Сверить перед заказом» в README.

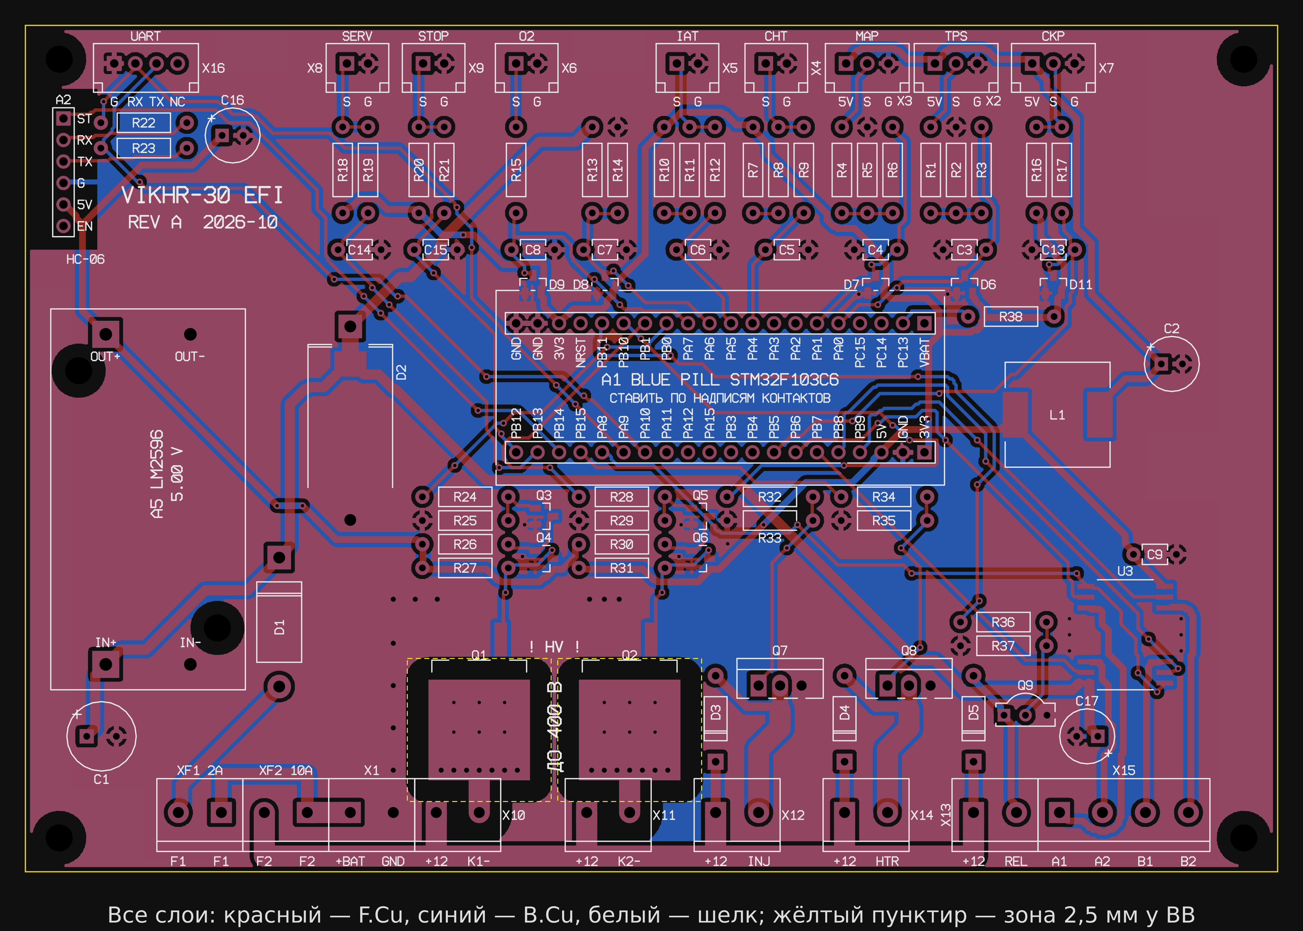
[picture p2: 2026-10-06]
pcb/out/all-layers.png

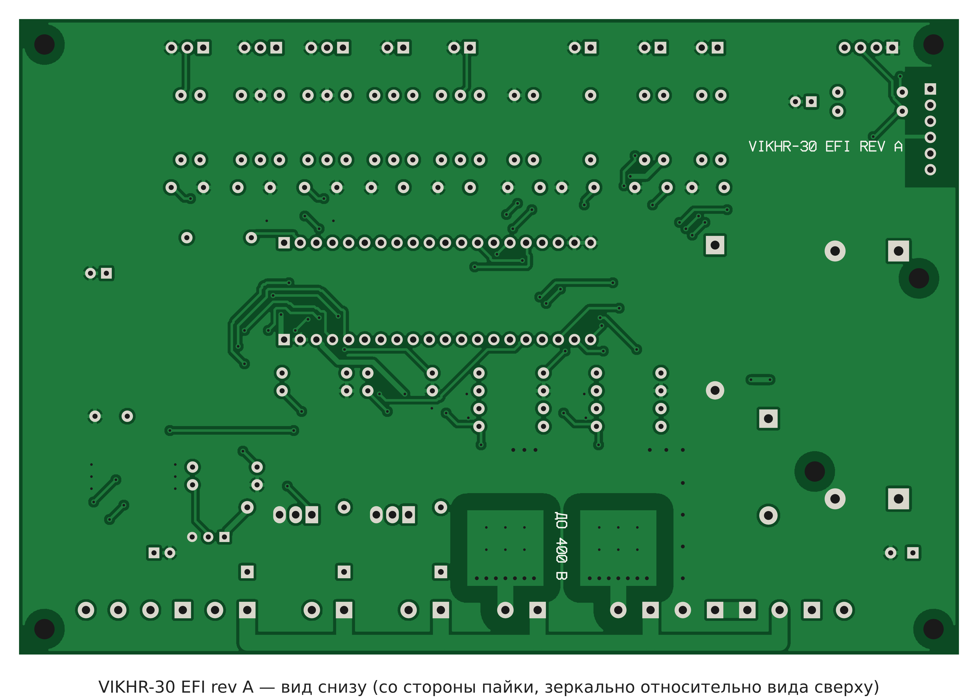
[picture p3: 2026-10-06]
pcb/out/bottom.png

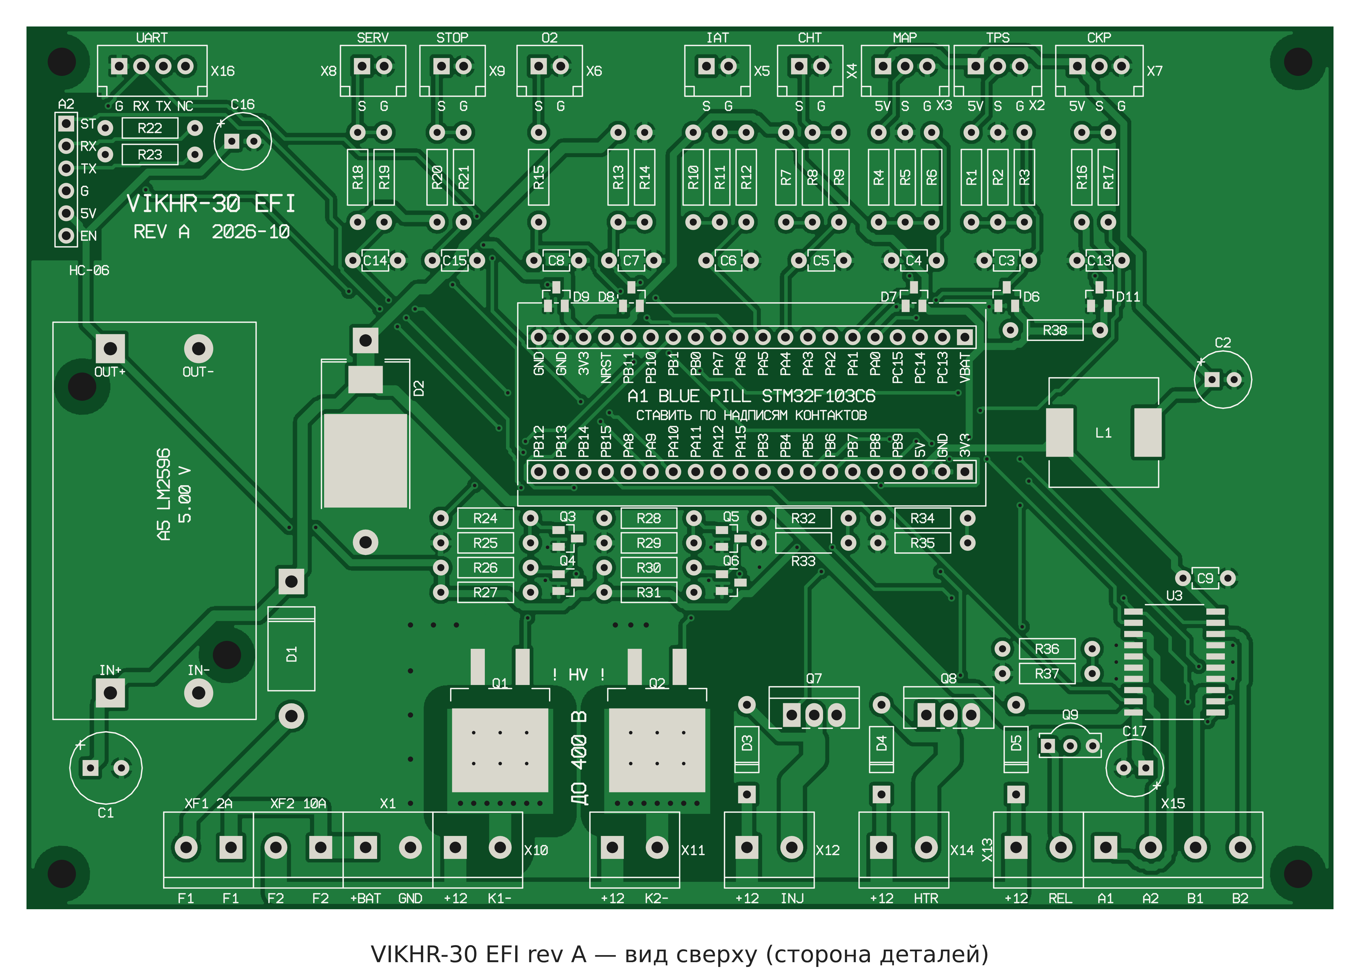
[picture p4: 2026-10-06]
pcb/out/top.png

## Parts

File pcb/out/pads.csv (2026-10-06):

ref | pin | x_mm | y_mm | type | net
A1 | JL1 | 106.2600 | 64.8000 | TH
A1 | JR1 | 106.2600 | 49.5600 | TH | V33
A1 | JL2 | 103.7200 | 64.8000 | TH | PC13
A1 | JR2 | 103.7200 | 49.5600 | TH | GND
A1 | JL3 | 101.1800 | 64.8000 | TH
A1 | JR3 | 101.1800 | 49.5600 | TH | V5
A1 | JL4 | 98.6400 | 64.8000 | TH
A1 | JR4 | 98.6400 | 49.5600 | TH | PB9
A1 | JL5 | 96.1000 | 64.8000 | TH | PA0
A1 | JR5 | 96.1000 | 49.5600 | TH | PB8
A1 | JL6 | 93.5600 | 64.8000 | TH | PA1
A1 | JR6 | 93.5600 | 49.5600 | TH | PB7
A1 | JL7 | 91.0200 | 64.8000 | TH
A1 | JR7 | 91.0200 | 49.5600 | TH | PB6
A1 | JL8 | 88.4800 | 64.8000 | TH
A1 | JR8 | 88.4800 | 49.5600 | TH | PB5
A1 | JL9 | 85.9400 | 64.8000 | TH | PA4
A1 | JR9 | 85.9400 | 49.5600 | TH
A1 | JL10 | 83.4000 | 64.8000 | TH | PA5
A1 | JR10 | 83.4000 | 49.5600 | TH
A1 | JL11 | 80.8600 | 64.8000 | TH | PA6
A1 | JR11 | 80.8600 | 49.5600 | TH
A1 | JL12 | 78.3200 | 64.8000 | TH | PA7
A1 | JR12 | 78.3200 | 49.5600 | TH
A1 | JL13 | 75.7800 | 64.8000 | TH | PB0
A1 | JR13 | 75.7800 | 49.5600 | TH
A1 | JL14 | 73.2400 | 64.8000 | TH | PB1
A1 | JR14 | 73.2400 | 49.5600 | TH | PA10
A1 | JL15 | 70.7000 | 64.8000 | TH | PB10
A1 | JR15 | 70.7000 | 49.5600 | TH | PA9
A1 | JL16 | 68.1600 | 64.8000 | TH | PB11
A1 | JR16 | 68.1600 | 49.5600 | TH | PA8
A1 | JL17 | 65.6200 | 64.8000 | TH
A1 | JR17 | 65.6200 | 49.5600 | TH | PB15
A1 | JL18 | 63.0800 | 64.8000 | TH | V33
A1 | JR18 | 63.0800 | 49.5600 | TH | PB14
A1 | JL19 | 60.5400 | 64.8000 | TH | GND
A1 | JR19 | 60.5400 | 49.5600 | TH | PB13
A1 | JL20 | 58.0000 | 64.8000 | TH | GND
A1 | JR20 | 58.0000 | 49.5600 | TH | PB12
A5 | 1 | 9.5000 | 24.5000 | TH | V12
A5 | 2 | 19.5000 | 24.5000 | TH | GND
A5 | 3 | 9.5000 | 63.5000 | TH | V5
A5 | 4 | 19.5000 | 63.5000 | TH | GND
A2 | 1 | 4.5000 | 89.0000 | TH | PB14
A2 | 2 | 4.5000 | 86.4600 | TH | PA9_A2
A2 | 3 | 4.5000 | 83.9200 | TH | PA10_A2
A2 | 4 | 4.5000 | 81.3800 | TH | GND
A2 | 5 | 4.5000 | 78.8400 | TH | V5
A2 | 6 | 4.5000 | 76.3000 | TH
X16 | 1 | 10.5000 | 95.5000 | TH | GND
X16 | 2 | 13.0000 | 95.5000 | TH | PA9
X16 | 3 | 15.5000 | 95.5000 | TH | PA10
X16 | 4 | 18.0000 | 95.5000 | TH
R22 | 1 | 8.9200 | 88.5000 | TH | PA9
R22 | 2 | 19.0800 | 88.5000 | TH | PA9_A2
R23 | 1 | 8.9200 | 85.5000 | TH | PA10
R23 | 2 | 19.0800 | 85.5000 | TH | PA10_A2
C16 | 1 | 23.2500 | 87.0000 | TH | V5
C16 | 2 | 25.7500 | 87.0000 | TH | GND
XF1 | 2 | 18.0800 | 7.0000 | TH | N_D1_A
XF1 | 1 | 23.1600 | 7.0000 | TH | BAT
XF2 | 2 | 28.2400 | 7.0000 | TH | F2
XF2 | 1 | 33.3200 | 7.0000 | TH | BAT
X1 | 1 | 38.4000 | 7.0000 | TH | BAT
X1 | 2 | 43.4800 | 7.0000 | TH | GND
D1 | 1 | 30.0000 | 37.1200 | TH | V12
D1 | 2 | 30.0000 | 21.8800 | TH | N_D1_A
D2 | 2 | 38.4000 | 50.8000 | SMD_TOP | GND
D2 | 1 | 38.4000 | 60.0000 | SMD_TOP | V12
D2 | 2 | 38.4000 | 41.5700 | TH | GND
D2 | 1 | 38.4000 | 64.4300 | TH | V12
C1 | 1 | 7.2500 | 16.0000 | TH | V12
C1 | 2 | 10.7500 | 16.0000 | TH | GND
L1 | 1 | 117.0000 | 54.0000 | SMD_TOP | V5
L1 | 2 | 127.0000 | 54.0000 | SMD_TOP | V5S
C2 | 1 | 134.2500 | 60.0000 | TH | V5S
C2 | 2 | 136.7500 | 60.0000 | TH | GND
X10 | 1 | 48.5600 | 7.0000 | TH | F2
X10 | 2 | 53.6400 | 7.0000 | TH | COIL1
X11 | 1 | 66.3400 | 7.0000 | TH | F2
X11 | 2 | 71.4200 | 7.0000 | TH | COIL2
Q1 | 2 | 53.6400 | 18.0000 | SMD_TOP | COIL1
Q1 | 1 | 56.1800 | 27.4500 | SMD_TOP | G1
Q1 | 3 | 51.1000 | 27.4500 | SMD_TOP | GND
Q2 | 2 | 71.4200 | 18.0000 | SMD_TOP | COIL2
Q2 | 1 | 73.9600 | 27.4500 | SMD_TOP | G2
Q2 | 3 | 68.8800 | 27.4500 | SMD_TOP | GND
R24 | 1 | 46.9200 | 44.3000 | TH | PB0
R24 | 2 | 57.0800 | 44.3000 | TH | N_Q3_1
R25 | 1 | 57.0800 | 41.5000 | TH | N_Q3_1
R25 | 2 | 46.9200 | 41.5000 | TH | GND
R26 | 1 | 46.9200 | 38.7000 | TH | V5
R26 | 2 | 57.0800 | 38.7000 | TH | N_Q3_3
R27 | 1 | 46.9200 | 35.9000 | TH | V5
R27 | 2 | 57.0800 | 35.9000 | TH | G1
Q3 | 1 | 60.2500 | 42.9500 | SMD_TOP | N_Q3_1
Q3 | 2 | 60.2500 | 41.0500 | SMD_TOP | GND
Q3 | 3 | 62.3500 | 42.0000 | SMD_TOP | N_Q3_3
Q4 | 1 | 60.2500 | 37.9500 | SMD_TOP | N_Q3_3
Q4 | 2 | 60.2500 | 36.0500 | SMD_TOP | GND
Q4 | 3 | 62.3500 | 37.0000 | SMD_TOP | G1
R28 | 1 | 65.4200 | 44.3000 | TH | PB1
R28 | 2 | 75.5800 | 44.3000 | TH | N_Q5_1
R29 | 1 | 75.5800 | 41.5000 | TH | N_Q5_1
R29 | 2 | 65.4200 | 41.5000 | TH | GND
R30 | 1 | 65.4200 | 38.7000 | TH | V5
R30 | 2 | 75.5800 | 38.7000 | TH | N_Q5_3
R31 | 1 | 65.4200 | 35.9000 | TH | V5
R31 | 2 | 75.5800 | 35.9000 | TH | G2
Q5 | 1 | 78.7500 | 42.9500 | SMD_TOP | N_Q5_1
Q5 | 2 | 78.7500 | 41.0500 | SMD_TOP | GND
Q5 | 3 | 80.8500 | 42.0000 | SMD_TOP | N_Q5_3
Q6 | 1 | 78.7500 | 37.9500 | SMD_TOP | N_Q5_3
Q6 | 2 | 78.7500 | 36.0500 | SMD_TOP | GND
Q6 | 3 | 80.8500 | 37.0000 | SMD_TOP | G2
X12 | 1 | 81.5800 | 7.0000 | TH | F2
X12 | 2 | 86.6600 | 7.0000 | TH | INJ
Q7 | 1 | 86.6600 | 22.0000 | TH | N_Q7_1
Q7 | 2 | 89.2000 | 22.0000 | TH | INJ
Q7 | 3 | 91.7400 | 22.0000 | TH | GND
D3 | 1 | 81.5800 | 13.0000 | TH | F2
D3 | 2 | 81.5800 | 23.1600 | TH | INJ
R32 | 1 | 82.9200 | 44.3000 | TH | PB10
R32 | 2 | 93.0800 | 44.3000 | TH | N_Q7_1
R33 | 1 | 93.0800 | 41.5000 | TH | N_Q7_1
R33 | 2 | 82.9200 | 41.5000 | TH | GND
X14 | 1 | 96.8200 | 7.0000 | TH | F2
X14 | 2 | 101.9000 | 7.0000 | TH | HEAT
Q8 | 1 | 101.9000 | 22.0000 | TH | N_Q8_1
Q8 | 2 | 104.4400 | 22.0000 | TH | HEAT
Q8 | 3 | 106.9800 | 22.0000 | TH | GND
D4 | 1 | 96.8200 | 13.0000 | TH | F2
D4 | 2 | 96.8200 | 23.1600 | TH | HEAT
R34 | 1 | 96.4200 | 44.3000 | TH | PB15
R34 | 2 | 106.5800 | 44.3000 | TH | N_Q8_1
R35 | 1 | 106.5800 | 41.5000 | TH | N_Q8_1
R35 | 2 | 96.4200 | 41.5000 | TH | GND
X13 | 1 | 112.0600 | 7.0000 | TH | F2
X13 | 2 | 117.1400 | 7.0000 | TH | RELAY
Q9 | 1 | 115.6600 | 18.5000 | TH | RELAY
Q9 | 2 | 118.2000 | 18.5000 | TH | N_Q9_2
Q9 | 3 | 120.7400 | 18.5000 | TH | GND
D5 | 1 | 112.0600 | 13.0000 | TH | F2
D5 | 2 | 112.0600 | 23.1600 | TH | RELAY
R36 | 1 | 110.5200 | 29.5000 | TH | PB11
R36 | 2 | 120.6800 | 29.5000 | TH | N_Q9_2
R37 | 1 | 120.6800 | 26.7000 | TH | N_Q9_2
R37 | 2 | 110.5200 | 26.7000 | TH | GND
X15 | 1 | 122.2200 | 7.0000 | TH | IAC_A1
X15 | 2 | 127.3000 | 7.0000 | TH | IAC_A2
X15 | 3 | 132.3800 | 7.0000 | TH | IAC_B1
X15 | 4 | 137.4600 | 7.0000 | TH | IAC_B2
U3 | 1 | 125.3500 | 33.7150 | SMD_TOP | PA8
U3 | 2 | 125.3500 | 32.4450 | SMD_TOP | PB6
U3 | 3 | 125.3500 | 31.1750 | SMD_TOP | IAC_A1
U3 | 4 | 125.3500 | 29.9050 | SMD_TOP | GND
U3 | 5 | 125.3500 | 28.6350 | SMD_TOP | GND
U3 | 6 | 125.3500 | 27.3650 | SMD_TOP | GND
U3 | 7 | 125.3500 | 26.0950 | SMD_TOP | GND
U3 | 8 | 125.3500 | 24.8250 | SMD_TOP | IAC_A2
U3 | 9 | 125.3500 | 23.5550 | SMD_TOP | PB7
U3 | 10 | 125.3500 | 22.2850 | SMD_TOP | V12
U3 | 11 | 134.6500 | 22.2850 | SMD_TOP | PA8
U3 | 12 | 134.6500 | 23.5550 | SMD_TOP | PB8
U3 | 13 | 134.6500 | 24.8250 | SMD_TOP | IAC_B1
U3 | 14 | 134.6500 | 26.0950 | SMD_TOP | GND
U3 | 15 | 134.6500 | 27.3650 | SMD_TOP | GND
U3 | 16 | 134.6500 | 28.6350 | SMD_TOP | GND
U3 | 17 | 134.6500 | 29.9050 | SMD_TOP | GND
U3 | 18 | 134.6500 | 31.1750 | SMD_TOP | IAC_B2
U3 | 19 | 134.6500 | 32.4450 | SMD_TOP | PB9
U3 | 20 | 134.6500 | 33.7150 | SMD_TOP | V5
C9 | 1 | 130.9600 | 37.5000 | TH | V5
C9 | 2 | 136.0400 | 37.5000 | TH | GND
C17 | 1 | 126.7500 | 16.0000 | TH | V12
C17 | 2 | 124.2500 | 16.0000 | TH | GND
X8 | 1 | 38.0000 | 95.5000 | TH | PB13_X8
X8 | 2 | 40.5000 | 95.5000 | TH | GND
X9 | 1 | 47.0000 | 95.5000 | TH | PB12_X9
X9 | 2 | 49.5000 | 95.5000 | TH | GND
X6 | 1 | 58.0000 | 95.5000 | TH | PA7_X6
X6 | 2 | 60.5000 | 95.5000 | TH | GND
X5 | 1 | 77.0000 | 95.5000 | TH | PA5_X5
X5 | 2 | 79.5000 | 95.5000 | TH | GND
X4 | 1 | 87.5000 | 95.5000 | TH | PA4_X4
X4 | 2 | 90.0000 | 95.5000 | TH | GND
X3 | 1 | 97.0000 | 95.5000 | TH | V5S
X3 | 2 | 99.5000 | 95.5000 | TH | MAP_SIG
X3 | 3 | 102.0000 | 95.5000 | TH | GND
X2 | 1 | 107.5000 | 95.5000 | TH | V5S
X2 | 2 | 110.0000 | 95.5000 | TH | TPS_SIG
X2 | 3 | 112.5000 | 95.5000 | TH | GND
X7 | 1 | 119.0000 | 95.5000 | TH | V5S
X7 | 2 | 121.5000 | 95.5000 | TH | PB5_X7
X7 | 3 | 124.0000 | 95.5000 | TH | GND
R18 | 1 | 37.5000 | 77.8400 | TH | V33
R18 | 2 | 37.5000 | 88.0000 | TH | PB13_X8
R19 | 1 | 40.5000 | 88.0000 | TH | PB13_X8
R19 | 2 | 40.5000 | 77.8400 | TH | PB13
C14 | 1 | 36.9600 | 73.5000 | TH | PB13
C14 | 2 | 42.0400 | 73.5000 | TH | GND
R20 | 1 | 46.5000 | 77.8400 | TH | V33
R20 | 2 | 46.5000 | 88.0000 | TH | PB12_X9
R21 | 1 | 49.5000 | 88.0000 | TH | PB12_X9
R21 | 2 | 49.5000 | 77.8400 | TH | PB12
C15 | 1 | 45.9600 | 73.5000 | TH | PB12
C15 | 2 | 51.0400 | 73.5000 | TH | GND
R15 | 1 | 58.0000 | 88.0000 | TH | PA7_X6
R15 | 2 | 58.0000 | 77.8400 | TH | PA7
C8 | 1 | 57.4600 | 73.5000 | TH | PA7
C8 | 2 | 62.5400 | 73.5000 | TH | GND
D9 | 1 | 59.0500 | 68.3500 | SMD_TOP | GND
D9 | 2 | 60.9500 | 68.3500 | SMD_TOP | V33
D9 | 3 | 60.0000 | 70.4500 | SMD_TOP | PA7
R13 | 1 | 67.0000 | 88.0000 | TH | V12
R13 | 2 | 67.0000 | 77.8400 | TH | PA6
R14 | 1 | 70.0000 | 77.8400 | TH | PA6
R14 | 2 | 70.0000 | 88.0000 | TH | GND
C7 | 1 | 65.9600 | 73.5000 | TH | PA6
C7 | 2 | 71.0400 | 73.5000 | TH | GND
D8 | 1 | 67.5500 | 68.3500 | SMD_TOP | GND
D8 | 2 | 69.4500 | 68.3500 | SMD_TOP | V33
D8 | 3 | 68.5000 | 70.4500 | SMD_TOP | PA6
R10 | 1 | 75.5000 | 88.0000 | TH | V33
R10 | 2 | 75.5000 | 77.8400 | TH | N_R10_2
R11 | 1 | 78.5000 | 77.8400 | TH | N_R10_2
R11 | 2 | 78.5000 | 88.0000 | TH | PA5_X5
R12 | 1 | 81.5000 | 88.0000 | TH | PA5_X5
R12 | 2 | 81.5000 | 77.8400 | TH | PA5
C6 | 1 | 76.9600 | 73.5000 | TH | PA5
C6 | 2 | 82.0400 | 73.5000 | TH | GND
R7 | 1 | 86.0000 | 88.0000 | TH | V33
R7 | 2 | 86.0000 | 77.8400 | TH | N_R7_2
R8 | 1 | 89.0000 | 77.8400 | TH | N_R7_2
R8 | 2 | 89.0000 | 88.0000 | TH | PA4_X4
R9 | 1 | 92.0000 | 88.0000 | TH | PA4_X4
R9 | 2 | 92.0000 | 77.8400 | TH | PA4
C5 | 1 | 87.4600 | 73.5000 | TH | PA4
C5 | 2 | 92.5400 | 73.5000 | TH | GND
R4 | 1 | 96.5000 | 88.0000 | TH | MAP_SIG
R4 | 2 | 96.5000 | 77.8400 | TH | N_R4_2
R5 | 1 | 99.5000 | 77.8400 | TH | N_R4_2
R5 | 2 | 99.5000 | 88.0000 | TH | GND
R6 | 1 | 102.5000 | 77.8400 | TH | N_R4_2
R6 | 2 | 102.5000 | 88.0000 | TH | PA1
C4 | 1 | 103.0400 | 73.5000 | TH | PA1
C4 | 2 | 97.9600 | 73.5000 | TH | GND
D7 | 1 | 99.5500 | 68.3500 | SMD_TOP | GND
D7 | 2 | 101.4500 | 68.3500 | SMD_TOP | V33
D7 | 3 | 100.5000 | 70.4500 | SMD_TOP | PA1
R1 | 1 | 107.0000 | 88.0000 | TH | TPS_SIG
R1 | 2 | 107.0000 | 77.8400 | TH | N_R1_2
R2 | 1 | 110.0000 | 77.8400 | TH | N_R1_2
R2 | 2 | 110.0000 | 88.0000 | TH | GND
R3 | 1 | 113.0000 | 77.8400 | TH | N_R1_2
R3 | 2 | 113.0000 | 88.0000 | TH | PA0
C3 | 1 | 113.5400 | 73.5000 | TH | PA0
C3 | 2 | 108.4600 | 73.5000 | TH | GND
D6 | 1 | 110.0500 | 68.3500 | SMD_TOP | GND
D6 | 2 | 111.9500 | 68.3500 | SMD_TOP | V33
D6 | 3 | 111.0000 | 70.4500 | SMD_TOP | PA0
R16 | 1 | 119.5000 | 77.8400 | TH | V33
R16 | 2 | 119.5000 | 88.0000 | TH | PB5_X7
R17 | 1 | 122.5000 | 88.0000 | TH | PB5_X7
R17 | 2 | 122.5000 | 77.8400 | TH | PB5
C13 | 1 | 124.0400 | 73.5000 | TH | PB5
C13 | 2 | 118.9600 | 73.5000 | TH | GND
D11 | 1 | 120.5500 | 68.3500 | SMD_TOP | GND
D11 | 2 | 122.4500 | 68.3500 | SMD_TOP | V33
D11 | 3 | 121.5000 | 70.4500 | SMD_TOP | PB5
R38 | 1 | 121.5800 | 65.6000 | TH | V33
R38 | 2 | 111.4200 | 65.6000 | TH | PC13

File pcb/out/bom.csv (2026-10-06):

Обозначение | Номинал / тип | Корпус (посадочное место) | Кол-во | Что купить (строка перечня программы) | Ссылка магазина
A1 | Blue Pill STM32F103C6T6 | BLUEPILL_2x20 | 1 | Плата STM32F103C6T6 (Blue Pill HW-267) | https://magazin-elektronika.ru/73-84-23
A2 | HC-06 | HDR_1x6 | 1 | Bluetooth-модуль HC-06 | https://magazin-elektronika.ru/78-00-66
A5 | LM2596S, 5,00 В | LM2596_MODULE | 1 | DC-DC модуль LM2596S (4–40 В → 5 В, 2 А) | https://magazin-elektronika.ru/78-96-44
C1 | 470 мкФ × 25 В | CP_D8_P3.5 | 1 | Конденсатор 470 мкФ × 25 В | https://magazin-elektronika.ru/99-01-97
C2, C16, C17 | 47 мкФ × 63 В | CP_D6.3_P2.5 | 3 | Конденсатор 47 мкФ × 63 В | https://magazin-elektronika.ru/99-02-36
C3, C4, C5, C6, C7, C8, C9 | 0,1 мкФ | C_DISC_5.08 | 7 | Конденсатор керамический 0,1 мкФ × 50 В | https://magazin-elektronika.ru/99-00-22
C13, C14, C15 | 1 нФ | C_DISC_5.08 | 3 | Конденсатор керамический 1 нФ × 50 В
D1 | SR560 | DO-201AD_15.24 | 1 | Диод Шоттки SR560 (5 А, 60 В) | https://magazin-elektronika.ru/99-42-50
D2 | SM8S30A | DO-218AB | 1 | TVS-диод SM8S30A | https://magazin-elektronika.ru/76-06-46
D3, D4, D5 | 1N4007 | DO-41_10.16 | 3 | Диод 1N4007 | https://magazin-elektronika.ru/99-43-56
D6, D7, D8, D9, D11 | BAR43S | SOT-23 | 5 | Сборка диодов Шоттки BAR43S (SOT-23) | https://magazin-elektronika.ru/76-18-88
L1 | 47 мкГн | CDRH125 | 1 | Дроссель 47 мкГн, 1,8 А (CDRH125) | https://magazin-elektronika.ru/75-99-72
Q1, Q2 | IRGS14C40L | TO-263-2 | 2 | IGBT зажигания IRGS14C40L (TO-263) | https://magazin-elektronika.ru/99-46-03
Q3, Q4, Q5, Q6 | AO3400A | SOT-23 | 4 | MOSFET AO3400A (SOT-23) | https://magazin-elektronika.ru/73-20-80
Q7, Q8 | IRLZ44N | TO-220_V | 2 | MOSFET IRLZ44N (TO-220) | https://magazin-elektronika.ru/99-46-44
Q9 | BC547C | TO-92 | 1 | Транзистор BC547C | https://magazin-elektronika.ru/99-52-75
R1, R4, R14, R15, R18, R20, R25, R29, R37, R38 | 10 кОм | R_AXIAL_10.16 | 10 | Резисторы 0,25 Вт: 91 Ом, 100 Ом, 330 Ом, 470 Ом, 1 кОм, 2,4 кОм, 4,7 кОм, 10 кОм, 20 кОм, 47 кОм, 100 кОм | https://magazin-elektronika.ru/elektronnye-komponenty/rezistory-13
R2, R5 | 20 кОм | R_AXIAL_10.16 | 2 | Резисторы 0,25 Вт: 91 Ом, 100 Ом, 330 Ом, 470 Ом, 1 кОм, 2,4 кОм, 4,7 кОм, 10 кОм, 20 кОм, 47 кОм, 100 кОм | https://magazin-elektronika.ru/elektronnye-komponenty/rezistory-13
R3, R6, R9, R12, R17, R19, R21, R22, R23, R26, R30, R36 | 1 кОм | R_AXIAL_10.16 | 12 | Резисторы 0,25 Вт: 91 Ом, 100 Ом, 330 Ом, 470 Ом, 1 кОм, 2,4 кОм, 4,7 кОм, 10 кОм, 20 кОм, 47 кОм, 100 кОм | https://magazin-elektronika.ru/elektronnye-komponenty/rezistory-13
R7, R10 | 2,4 кОм | R_AXIAL_10.16 | 2 | Резисторы 0,25 Вт: 91 Ом, 100 Ом, 330 Ом, 470 Ом, 1 кОм, 2,4 кОм, 4,7 кОм, 10 кОм, 20 кОм, 47 кОм, 100 кОм | https://magazin-elektronika.ru/elektronnye-komponenty/rezistory-13
R8, R11 | 91 Ом | R_AXIAL_10.16 | 2 | Резисторы 0,25 Вт: 91 Ом, 100 Ом, 330 Ом, 470 Ом, 1 кОм, 2,4 кОм, 4,7 кОм, 10 кОм, 20 кОм, 47 кОм, 100 кОм | https://magazin-elektronika.ru/elektronnye-komponenty/rezistory-13
R13 | 47 кОм | R_AXIAL_10.16 | 1 | Резисторы 0,25 Вт: 91 Ом, 100 Ом, 330 Ом, 470 Ом, 1 кОм, 2,4 кОм, 4,7 кОм, 10 кОм, 20 кОм, 47 кОм, 100 кОм | https://magazin-elektronika.ru/elektronnye-komponenty/rezistory-13
R16 | 4,7 кОм | R_AXIAL_10.16 | 1 | Резисторы 0,25 Вт: 91 Ом, 100 Ом, 330 Ом, 470 Ом, 1 кОм, 2,4 кОм, 4,7 кОм, 10 кОм, 20 кОм, 47 кОм, 100 кОм | https://magazin-elektronika.ru/elektronnye-komponenty/rezistory-13
R24, R28 | 330 Ом | R_AXIAL_10.16 | 2 | Резисторы 0,25 Вт: 91 Ом, 100 Ом, 330 Ом, 470 Ом, 1 кОм, 2,4 кОм, 4,7 кОм, 10 кОм, 20 кОм, 47 кОм, 100 кОм | https://magazin-elektronika.ru/elektronnye-komponenty/rezistory-13
R27, R31 | 470 Ом | R_AXIAL_10.16 | 2 | Резисторы 0,25 Вт: 91 Ом, 100 Ом, 330 Ом, 470 Ом, 1 кОм, 2,4 кОм, 4,7 кОм, 10 кОм, 20 кОм, 47 кОм, 100 кОм | https://magazin-elektronika.ru/elektronnye-komponenty/rezistory-13
R32, R34 | 100 Ом | R_AXIAL_10.16 | 2 | Резисторы 0,25 Вт: 91 Ом, 100 Ом, 330 Ом, 470 Ом, 1 кОм, 2,4 кОм, 4,7 кОм, 10 кОм, 20 кОм, 47 кОм, 100 кОм | https://magazin-elektronika.ru/elektronnye-komponenty/rezistory-13
R33, R35 | 100 кОм | R_AXIAL_10.16 | 2 | Резисторы 0,25 Вт: 91 Ом, 100 Ом, 330 Ом, 470 Ом, 1 кОм, 2,4 кОм, 4,7 кОм, 10 кОм, 20 кОм, 47 кОм, 100 кОм | https://magazin-elektronika.ru/elektronnye-komponenty/rezistory-13
U3 | L293DD | SO-20W | 1 | Драйвер L293DD (SO-20) | https://magazin-elektronika.ru/99-86-61
X1, X10, X11, X12, X13, X14 | Клеммник 2 конт. | TERM_5.08_2 | 6 | Клеммник разъёмный 5,08 мм 2 контакта | https://magazin-elektronika.ru/98-19-50
X2, X3, X7 | JST XH 3 конт. | JST_XH_3 | 3 | Набор разъёмов JST XH 2,54 (2–5 контактов) | https://magazin-elektronika.ru/74-68-09
X4, X5, X6, X8, X9 | JST XH 2 конт. | JST_XH_2 | 5 | Набор разъёмов JST XH 2,54 (2–5 контактов) | https://magazin-elektronika.ru/74-68-09
X15 | Клеммник 4 конт. 5,08 (на схеме — JST XH 4 конт.) | TERM_5.08_4 | 1 | Клеммник разъёмный 5,08 мм — 2 шт. по 2 контакта или один на 4
X16 | JST XH 4 конт. (USB-UART A3) | JST_XH_4 | 1 | Набор разъёмов JST XH 2,54 (2–5 контактов)
XF1 | Клеммник 2 конт. к держателю F1 (2 А) | TERM_5.08_2R | 1 | Клеммник разъёмный 5,08 мм 2 контакта
XF2 | Клеммник 2 конт. к держателю F2 (10 А) | TERM_5.08_2R | 1 | Клеммник разъёмный 5,08 мм 2 контакта
— | Гнездо PBS-1x20 под A1 | в посадочном месте A1 | 2 | Гнездо PBS-1x20 (или 2 × 1x10), 2,54 мм | https://magazin-elektronika.ru/74-61-86
— | Гнездо PBS-1x6 под A2 (HC-06) | HDR_1x6 | 1 | из линейки PBS, 2,54 мм
— | Стойки М3 для модуля A5 и крепежа платы |  | 6

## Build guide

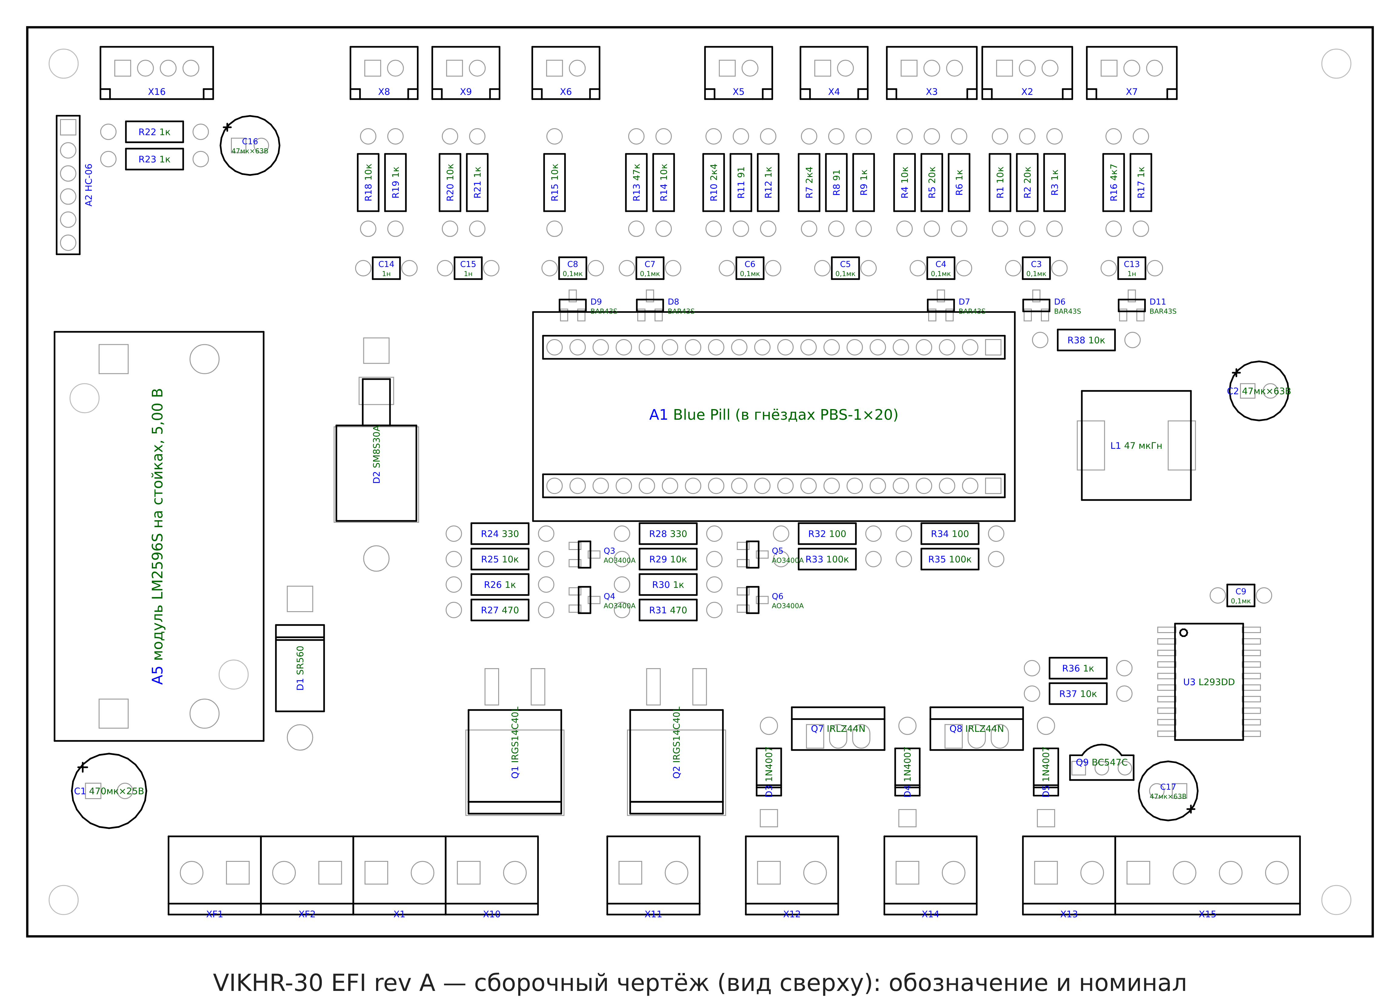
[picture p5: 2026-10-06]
pcb/out/assembly.png

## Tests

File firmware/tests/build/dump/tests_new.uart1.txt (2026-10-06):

BOOTSTAGE,UART_READY,HSI_PLL64
BOOTSTAGE,HW_READY
BOOT,VIKHR30_STM32,0.9.0-C6-BT-DIAG,DEFAULTS
OK
OK,VIKHR30_STM32,0.9.0-C6-BT-DIAG
ERR,service_lock
ERR,service_lock
ERR,service_lock
ERR,service_lock
ERR,service_lock
ERR,service_lock
OK,TEST,INJECTOR
TEST,DONE,INJECTOR
OK,TEST,COIL1
TEST,DONE,COIL1
OK,TEST,COIL2
TEST,DONE,COIL2
OK,TEST,IAC_OPEN
TEST,DONE,IAC_OPEN
OK,TEST,IAC_CLOSE
TEST,DONE,IAC_CLOSE
OK,TEST,PUMP
TEST,DONE,PUMP
OK,TEST,O2_HEATER
TEST,DONE,O2_HEATER
OK,TEST,STOP
ERR,bad_test
ERR,unknown_command
ERR,unknown_command
ERR,index
OK
OK
OK
ERR,unknown_parameter
ERR,bad_set
ERR,bad_get
OK
OK
OK,TEST,COIL1
TEST,DONE,COIL1
OK,SAVED
OK,TEST,INJECTOR
TEST,DONE,INJECTOR
OK,SAVED
ERR,service_lock
ERR,service_lock
ERR,service_lock
OK,TEST,STOP

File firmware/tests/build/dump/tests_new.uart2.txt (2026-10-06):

BOOTSTAGE,UART_READY,HSI_PLL64
BOOTSTAGE,HW_READY
BOOT,VIKHR30_STM32,0.9.0-C6-BT-DIAG,DEFAULTS
OK
TEST,DONE,INJECTOR
TEST,DONE,COIL1
TEST,DONE,COIL2
TEST,DONE,IAC_OPEN
TEST,DONE,IAC_CLOSE
TEST,DONE,PUMP
TEST,DONE,O2_HEATER
TEST,DONE,COIL1
TEST,DONE,INJECTOR
OK,VIKHR30_STM32,0.9.0-C6-BT-DIAG
ERR,service_lock

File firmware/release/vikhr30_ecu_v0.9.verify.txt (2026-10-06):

[PASS] неразрешённые символы: нет
[PASS] начальный SP: 0x20002800
[PASS] вектор сброса: 0x080000F1 = Reset_Handler 0x080000F0 + бит Thumb
[PASS] вектор 15 = SysTick_Handler: 0x0800014B, функция по адресу 0x0800014A
[PASS] вектор 39 (IRQ 23) = EXTI9_5_IRQHandler: 0x0800032D, функция по адресу 0x0800032C
[PASS] вектор 44 (IRQ 28) = TIM2_IRQHandler: 0x080001D7, функция по адресу 0x080001D6
[PASS] вектор 53 (IRQ 37) = USART1_IRQHandler: 0x0800015B, функция по адресу 0x0800015A
[PASS] вектор 54 (IRQ 38) = USART2_IRQHandler: 0x080001CB, функция по адресу 0x080001CA
[PASS] остальные векторы: Default_Handler или 0
[PASS] таблица векторов в начале Flash: 0x08000000
[PASS] размер образа: 17992 байт (17.57 КБ) из 31744; свободно 13752; страница калибровок 0x08007C00 не затронута
[PASS] ОЗУ: .data+.bss = 6208 байт, под стек остаётся 4032 байт из 10240
[PASS] секции: .isr_vector 236, .text 17724, .data 32, .bss 6176
[PASS] строка версии: 0.9.0-C6-BT-DIAG присутствует в образе
[PASS] HEX = BIN: 17992 байт данных, адреса 0x08000000…0x08004647, контрольные суммы записей верны, побайтно совпадает с BIN, запись точки входа 0x080000F1
[PASS] HEX не трогает страницу калибровок: последний адрес 0x08004647 < 0x08007C00

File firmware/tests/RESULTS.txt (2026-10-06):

Vikhr-30 ECU: проверка прошивки на симуляторе (хост)
Симулятор: TIM2 16 бит, 1 МГц; UART 115200; полный режим
NEW = v0.9 (src/main.c), OLD = v0.8 (tests/v0.8/main.c, без изменений)

== (а)(б) Постоянные обороты, >= 3,2 с измерения на каждый режим ==
[PASS] 300 об/мин NEW: искр 32, пропущено 0, лишних 0; впрысков 32, пропущено 0; ош. впрыска ≤2.7 мкс, ош. накопления ≤1.1 мкс, ош. УОЗ ≤0.01° (средн. 0.00°); зубьев без синхр. 0/560; катушка под током ≤1.60 мс, форсунка открыта ≤2.15 мс; метки времени зубьев: неверных 0 из 692; переполнений TIM2 62
[info] 300 об/мин OLD: искр 0, пропущено 32, лишних 0; впрысков 13, пропущено 19; ош. впрыска ≤2122.8 мкс, ош. накопления ≤0.0 мкс, ош. УОЗ ≤0.00° (средн. 0.00°); зубьев без синхр. 518/560; катушка под током ≤0.00 мс, форсунка открыта ≤2.15 мс; метки времени зубьев: неверных 632 из 632
[PASS] 450 об/мин NEW: искр 48, пропущено 0, лишних 0; впрысков 48, пропущено 0; ош. впрыска ≤2.9 мкс, ош. накопления ≤1.1 мкс, ош. УОЗ ≤0.01° (средн. 0.01°); зубьев без синхр. 0/840; катушка под током ≤1.60 мс, форсунка открыта ≤2.16 мс; метки времени зубьев: неверных 0 из 972; переполнений TIM2 58
[info] 450 об/мин OLD: искр 0, пропущено 48, лишних 0; впрысков 20, пропущено 28; ош. впрыска ≤2123.5 мкс, ош. накопления ≤0.0 мкс, ош. УОЗ ≤0.00° (средн. 0.00°); зубьев без синхр. 771/840; катушка под током ≤0.00 мс, форсунка открыта ≤2.18 мс; метки времени зубьев: неверных 915 из 915
[PASS] 600 об/мин NEW: искр 64, пропущено 0, лишних 0; впрысков 64, пропущено 0; ош. впрыска ≤2.8 мкс, ош. накопления ≤1.1 мкс, ош. УОЗ ≤0.02° (средн. 0.01°); зубьев без синхр. 0/1120; катушка под током ≤1.60 мс, форсунка открыта ≤2.17 мс; метки времени зубьев: неверных 0 из 1287; переполнений TIM2 57
[info] 600 об/мин OLD: искр 0, пропущено 64, лишних 0; впрысков 32, пропущено 32; ош. впрыска ≤42308.6 мкс, ош. накопления ≤0.0 мкс, ош. УОЗ ≤0.00° (средн. 0.00°); зубьев без синхр. 891/1120; катушка под током ≤0.00 мс, форсунка открыта ≤44.44 мс; метки времени зубьев: неверных 1231 из 1231
[PASS] 1100 об/мин NEW: искр 117, пропущено 0, лишних 0; впрысков 117, пропущено 0; ош. впрыска ≤3.0 мкс, ош. накопления ≤1.1 мкс, ош. УОЗ ≤0.06° (средн. -0.03°); зубьев без синхр. 0/2054; катушка под током ≤1.60 мс, форсунка открыта ≤2.08 мс; метки времени зубьев: неверных 0 из 2367; переполнений TIM2 57
[info] 1100 об/мин OLD: искр 3, пропущено 114, лишних 0; впрысков 58, пропущено 59; ош. впрыска ≤2123.3 мкс, ош. накопления ≤9852.6 мкс, ош. УОЗ ≤65.03° (средн. -21.69°); зубьев без синхр. 1785/2055; катушка под током ≤11.45 мс, форсунка открыта ≤2.18 мс; метки времени зубьев: неверных 2311 из 2311
[PASS] 3000 об/мин NEW: искр 320, пропущено 0, лишних 0; впрысков 320, пропущено 0; ош. впрыска ≤3.1 мкс, ош. накопления ≤1.1 мкс, ош. УОЗ ≤0.06° (средн. 0.02°); зубьев без синхр. 0/5599; катушка под током ≤1.60 мс, форсунка открыта ≤2.07 мс; метки времени зубьев: неверных 0 из 6467; переполнений TIM2 57
[info] 3000 об/мин OLD: искр 57, пропущено 263, лишних 0; впрысков 187, пропущено 133; ош. впрыска ≤10559.0 мкс, ош. накопления ≤13076.5 мкс, ош. УОЗ ≤145.29° (средн. -1.20°); зубьев без синхр. 4054/5600; катушка под током ≤14.68 мс, форсунка открыта ≤12.55 мс; метки времени зубьев: неверных 6411 из 6411
[PASS] 6000 об/мин NEW: искр 640, пропущено 0, лишних 0; впрысков 640, пропущено 0; ош. впрыска ≤3.0 мкс, ош. накопления ≤4.2 мкс, ош. УОЗ ≤0.18° (средн. 0.12°); зубьев без синхр. 0/11199; катушка под током ≤1.60 мс, форсунка открыта ≤2.23 мс; метки времени зубьев: неверных 0 из 12942; переполнений TIM2 57
[info] 6000 об/мин OLD: искр 170, пропущено 470, лишних 0; впрысков 388, пропущено 251; ош. впрыска ≤5281.1 мкс, ош. накопления ≤10003.3 мкс, ош. УОЗ ≤72.39° (средн. 2.98°); зубьев без синхр. 7680/11199; катушка под током ≤11.60 мс, форсунка открыта ≤7.23 мс; метки времени зубьев: неверных 12886 из 12886
[PASS] 7000 об/мин NEW: искр 747, пропущено 0, лишних 0; впрысков 746, пропущено 0; ош. впрыска ≤3.1 мкс, ош. накопления ≤3.9 мкс, ош. УОЗ ≤0.54° (средн. -0.22°); зубьев без синхр. 0/13067; катушка под током ≤1.60 мс, форсунка открыта ≤2.23 мс; метки времени зубьев: неверных 0 из 15101; переполнений TIM2 57
[info] 7000 об/мин OLD: искр 141, пропущено 606, лишних 0; впрысков 440, пропущено 306; ош. впрыска ≤4527.9 мкс, ош. накопления ≤8103.1 мкс, ош. УОЗ ≤109.59° (средн. 3.10°); зубьев без синхр. 9846/13066; катушка под током ≤9.70 мс, форсунка открыта ≤6.45 мс; метки времени зубьев: неверных 15045 из 15045

== Контрольный опыт: v0.8 на ВООБРАЖАЕМОМ 32-разрядном TIM2 (такого в F103 нет) ==
[info] 3000 об/мин OLD, TIM2=32 бит: искр 12, пропущено 308, лишних 0; впрысков 166, пропущено 154; ош. впрыска ≤1979.8 мкс, ош. накопления ≤3.2 мкс, ош. УОЗ ≤0.06° (средн. 0.04°); зубьев без синхр. 5250/5600; катушка под током ≤1.60 мс, форсунка открыта ≤2.17 мс; метки времени зубьев: неверных 0 из 6467
[info] вывод: даже с 32-битным счётчиком v0.8 теряет синхронизацию: основной цикл читает время ДО чтения метки последнего зуба (гонка в обнаружении остановки), это отдельная ошибка помимо Ф1

== (а)(б) Разгон и торможение ==
[PASS] 600→6000 об/мин за 1500 мс, весь прогон NEW: искр 539, впрысков 539, потерь нет; ош. накопления ≤4.2 мкс, ош. впрыска ≤4.6 мкс; катушка ≤1.60 мс; ош. УОЗ во время изменения оборотов до 31.0° (см. README: ограничение алгоритма, не таймера)
[PASS] 600→6000, установившийся режим после NEW: искр 300, пропущено 0, лишних 0; впрысков 300, пропущено 0; ош. впрыска ≤3.1 мкс, ош. накопления ≤4.2 мкс, ош. УОЗ ≤0.18° (средн. 0.11°); зубьев без синхр. 0/5250; катушка под током ≤1.60 мс, форсунка открыта ≤2.17 мс; метки времени зубьев: неверных 0 из 9600
[info] 600→6000 OLD (весь прогон): искр 84, пропущено 455, лишних 0; впрысков 310, пропущено 229; ош. впрыска ≤5002.4 мкс, ош. накопления ≤10002.3 мкс, ош. УОЗ ≤175.20° (средн. 3.27°); зубьев без синхр. 7685/9432; катушка под током ≤11.60 мс, форсунка открыта ≤6.95 мс; метки времени зубьев: неверных 9531 из 9531
[PASS] 6000→900 об/мин за 1500 мс, весь прогон NEW: искр 366, впрысков 367, потерь нет; ош. накопления ≤4.0 мкс, ош. впрыска ≤3.3 мкс; катушка ≤1.60 мс; ош. УОЗ во время изменения оборотов до 14.4° (см. README: ограничение алгоритма, не таймера)
[PASS] 6000→900, установившийся режим после NEW: искр 45, пропущено 0, лишних 0; впрысков 45, пропущено 0; ош. впрыска ≤3.0 мкс, ош. накопления ≤1.1 мкс, ош. УОЗ ≤0.03° (средн. 0.02°); зубьев без синхр. 0/787; катушка под током ≤1.60 мс, форсунка открыта ≤2.23 мс; метки времени зубьев: неверных 0 из 8156
[info] 6000→900 OLD (весь прогон): искр 63, пропущено 303, лишних 0; впрысков 210, пропущено 157; ош. впрыска ≤5678.3 мкс, ош. накопления ≤2018.2 мкс, ош. УОЗ ≤72.39° (средн. 1.94°); зубьев без синхр. 4900/6414; катушка под током ≤3.62 мс, форсунка открыта ≤7.65 мс; метки времени зубьев: неверных 8087 из 8087
[PASS] 300→1100 об/мин за 600 мс, весь прогон NEW: искр 87, впрысков 87, потерь нет; ош. накопления ≤1.1 мкс, ош. впрыска ≤2.7 мкс; катушка ≤1.60 мс; ош. УОЗ во время изменения оборотов до 48.5° (см. README: ограничение алгоритма, не таймера)
[PASS] 300→1100, установившийся режим после NEW: искр 55, пропущено 0, лишних 0; впрысков 55, пропущено 0; ош. впрыска ≤2.7 мкс, ош. накопления ≤1.1 мкс, ош. УОЗ ≤0.05° (средн. -0.03°); зубьев без синхр. 0/964; катушка под током ≤1.60 мс, форсунка открыта ≤2.15 мс; метки времени зубьев: неверных 0 из 1655
[info] 300→1100 OLD (весь прогон): искр 2, пропущено 85, лишних 0; впрысков 46, пропущено 41; ош. впрыска ≤21173.5 мкс, ош. накопления ≤2.1 мкс, ош. УОЗ ≤0.02° (средн. -0.02°); зубьев без синхр. 1295/1523; катушка под током ≤1.60 мс, форсунка открыта ≤23.29 мс; метки времени зубьев: неверных 1596 из 1596
[PASS] 3000→7000 об/мин за 800 мс, весь прогон NEW: искр 623, впрысков 623, потерь нет; ош. накопления ≤4.1 мкс, ош. впрыска ≤4.7 мкс; катушка ≤1.61 мс; ош. УОЗ во время изменения оборотов до 2.1° (см. README: ограничение алгоритма, не таймера)
[PASS] 3000→7000, установившийся режим после NEW: искр 350, пропущено 0, лишних 0; впрысков 350, пропущено 0; ош. впрыска ≤3.0 мкс, ош. накопления ≤4.1 мкс, ош. УОЗ ≤0.52° (средн. -0.23°); зубьев без синхр. 0/6125; катушка под током ≤1.61 мс, форсунка открыта ≤2.07 мс; метки времени зубьев: неверных 0 из 11776
[info] 3000→7000 OLD (весь прогон): искр 119, пропущено 504, лишних 0; впрысков 365, пропущено 258; ош. впрыска ≤8841.1 мкс, ош. накопления ≤8577.0 мкс, ош. УОЗ ≤145.29° (средн. 4.35°); зубьев без синхр. 8171/10909; катушка под током ≤10.18 мс, форсунка открыта ≤10.83 мс; метки времени зубьев: неверных 11718 из 11718
[PASS] 1100→6000 об/мин за 4000 мс, весь прогон NEW: искр 859, впрысков 858, потерь нет; ош. накопления ≤3.6 мкс, ош. впрыска ≤5.4 мкс; катушка ≤1.60 мс; ош. УОЗ во время изменения оборотов до 4.3° (см. README: ограничение алгоритма, не таймера)
[PASS] 1100→6000, установившийся режим после NEW: искр 300, пропущено 0, лишних 0; впрысков 300, пропущено 0; ош. впрыска ≤2.8 мкс, ош. накопления ≤3.6 мкс, ош. УОЗ ≤0.16° (средн. 0.08°); зубьев без синхр. 0/5250; катушка под током ≤1.60 мс, форсунка открыта ≤2.08 мс; метки времени зубьев: неверных 0 из 15346
[info] 1100→6000 OLD (весь прогон): искр 189, пропущено 670, лишних 0; впрысков 520, пропущено 339; ош. впрыска ≤8591.9 мкс, ош. накопления ≤8032.2 мкс, ош. УОЗ ≤166.31° (средн. 6.48°); зубьев без синхр. 10854/15033; катушка под током ≤9.63 мс, форсунка открыта ≤10.59 мс; метки времени зубьев: неверных 15238 из 15238

== (б)(в) Внезапное пропадание сигнала венца в разные моменты оборота ==
[PASS] 300 об/мин, 40 моментов остановки NEW: катушка под током ≤1.60 мс, форсунка ≤2.15 мс, остановка обнаружена через 240…250 мс, включений выходов после обнаружения 0, прогонов с rpm/sync≠0 в конце 0, с включённым выходом в конце 0
[info] 300 об/мин OLD: катушка под током ≤0.00 мс, форсунка ≤2.15 мс, остановка обнаружена через 0…64 мс, включений выходов после обнаружения 0, прогонов с rpm/sync≠0 в конце 0, с включённым выходом в конце 0 (малое время «обнаружения» у OLD — это ложные срабатывания на работающем двигателе)
[PASS] 1100 об/мин, 40 моментов остановки NEW: катушка под током ≤1.60 мс, форсунка ≤2.08 мс, остановка обнаружена через 247…250 мс, включений выходов после обнаружения 0, прогонов с rpm/sync≠0 в конце 0, с включённым выходом в конце 0
[info] 1100 об/мин OLD: катушка под током ≤1.60 мс, форсунка ≤2.18 мс, остановка обнаружена через 0…61 мс, включений выходов после обнаружения 0, прогонов с rpm/sync≠0 в конце 0, с включённым выходом в конце 0 (малое время «обнаружения» у OLD — это ложные срабатывания на работающем двигателе)
[PASS] 3000 об/мин, 40 моментов остановки NEW: катушка под током ≤1.60 мс, форсунка ≤2.07 мс, остановка обнаружена через 249…250 мс, включений выходов после обнаружения 0, прогонов с rpm/sync≠0 в конце 0, с включённым выходом в конце 0
[info] 3000 об/мин OLD: катушка под током ≤66.62 мс, форсунка ≤2.17 мс, остановка обнаружена через 2…64 мс, включений выходов после обнаружения 2500, прогонов с rpm/sync≠0 в конце 0, с включённым выходом в конце 0 (малое время «обнаружения» у OLD — это ложные срабатывания на работающем двигателе)
[PASS] 6000 об/мин, 40 моментов остановки NEW: катушка под током ≤1.60 мс, форсунка ≤2.23 мс, остановка обнаружена через 249…250 мс, включений выходов после обнаружения 0, прогонов с rpm/sync≠0 в конце 0, с включённым выходом в конце 0
[info] 6000 об/мин OLD: катушка под током ≤1.61 мс, форсунка ≤2.27 мс, остановка обнаружена через 7…20 мс, включений выходов после обнаружения 0, прогонов с rpm/sync≠0 в конце 0, с включённым выходом в конце 0 (малое время «обнаружения» у OLD — это ложные срабатывания на работающем двигателе)

== (б) Сбои синхронизации (пропавшие и лишние импульсы), перезапуск, ограничитель, аварийный выключатель ==
[PASS] сбои венца 600 об/мин NEW: катушка ≤1.60 мс, форсунка ≤2.17 мс, в конце sync=1, искр с ошибкой >2°: 16 из 81
[info] сбои венца 600 об/мин OLD: катушка ≤0.33 мс, форсунка ≤38.89 мс, в конце sync=0, искр с ошибкой >2°: 1 из 1
[PASS] сбои венца 3000 об/мин NEW: катушка ≤1.60 мс, форсунка ≤3.66 мс, в конце sync=1, искр с ошибкой >2°: 13 из 82
[info] сбои венца 3000 об/мин OLD: катушка ≤6.43 мс, форсунка ≤12.55 мс, в конце sync=0, искр с ошибкой >2°: 4 из 17
[PASS] перезапуск: 3000 → обрыв сигнала → прокрутка 300 об/мин NEW: искр 30, пропущено 0, лишних 0; впрысков 30, пропущено 0; ош. впрыска ≤2.0 мкс, ош. накопления ≤0.4 мкс, ош. УОЗ ≤0.00° (средн. -0.00°); зубьев без синхр. 0/525; катушка под током ≤1.60 мс, форсунка открыта ≤2.14 мс; метки времени зубьев: неверных 0 из 2616
[info] перезапуск OLD (прокрутка 300 об/мин): искр 348, пропущено 15, лишних 334; впрысков 477, пропущено 0; ош. впрыска ≤11114.0 мкс, ош. накопления ≤16670.6 мкс, ош. УОЗ ≤201.69° (средн. -22.30°); зубьев без синхр. 124/526; катушка под током ≤18.27 мс, форсунка открыта ≤13.10 мс; метки времени зубьев: неверных 2539 из 2539
[PASS] два импульса помехи (60 мкс) за 10 мс до начала прокрутки 300 об/мин NEW: через 1 с после начала прокрутки: искр 30, пропущено 0, лишних 0; впрысков 30, пропущено 0; ош. впрыска ≤3.1 мкс, ош. накопления ≤1.1 мкс, ош. УОЗ ≤0.01° (средн. 0.00°); зубьев без синхр. 0/525; катушка под током ≤1.60 мс, форсунка открыта ≤2.14 мс; метки времени зубьев: неверных 0 из 694
[info] то же OLD: rpm по мнению блока = 12000; искр 0, пропущено 30, лишних 0; впрысков 0, пропущено 30; ош. впрыска ≤0.0 мкс, ош. накопления ≤0.0 мкс, ош. УОЗ ≤0.00° (средн. 0.00°); зубьев без синхр. 179/525; катушка под током ≤0.00 мс, форсунка открыта ≤0.00 мс; метки времени зубьев: неверных 633 из 633
[info] то же, первая секунда прокрутки NEW: искр 8, из них с ошибкой УОЗ >2°: 2 (до 35° в сторону запаздывания, пока фильтр периода не сошёлся)
[PASS] жёсткий ограничитель 7150 об/мин (порог 7000) NEW: искр 0, впрысков 0, fault_flags=288
[PASS] мягкий ограничитель 6900 об/мин (порог 6800) NEW: искр 230, пропущено 230 (поведение v0.8 сохранено: отсекается каждый второй такт, т. е. всегда один и тот же цилиндр)
[info] жёсткий ограничитель OLD: искр 0, впрысков 0
[PASS] аварийный выключатель (PB12) на 3000 об/мин NEW: до выключателя: 90 искр без потерь; после: искр 0, впрысков 0
[info] аварийный выключатель OLD: после: искр 0, впрысков 0

== Чувствительность к модели быстродействия (цена одного обращения к памяти) ==
(основные прогоны: 100 нс; 300 нс — заведомо медленнее реального процессора, допуски для него 20 мкс и 2°)
[PASS] 600 об/мин, 50 нс/обращение NEW: искр 64, пропущено 0, лишних 0; впрысков 64, пропущено 0; ош. впрыска ≤1.5 мкс, ош. накопления ≤0.6 мкс, ош. УОЗ ≤0.03° (средн. 0.02°); зубьев без синхр. 0/1120; катушка под током ≤1.60 мс, форсунка открыта ≤2.17 мс; метки времени зубьев: неверных 0 из 1287
[PASS] 6000 об/мин, 50 нс/обращение NEW: искр 640, пропущено 0, лишних 0; впрысков 640, пропущено 0; ош. впрыска ≤1.6 мкс, ош. накопления ≤2.3 мкс, ош. УОЗ ≤0.22° (средн. 0.15°); зубьев без синхр. 0/11201; катушка под током ≤1.60 мс, форсунка открыта ≤2.23 мс; метки времени зубьев: неверных 0 из 12942
[PASS] 7000 об/мин, 50 нс/обращение NEW: искр 747, пропущено 0, лишних 0; впрысков 746, пропущено 0; ош. впрыска ≤1.5 мкс, ош. накопления ≤1.8 мкс, ош. УОЗ ≤0.41° (средн. -0.20°); зубьев без синхр. 0/13067; катушка под током ≤1.60 мс, форсунка открыта ≤2.23 мс; метки времени зубьев: неверных 0 из 15101
[PASS] 600 об/мин, 300 нс/обращение NEW: искр 64, пропущено 0, лишних 0; впрысков 64, пропущено 0; ош. впрыска ≤8.1 мкс, ош. накопления ≤3.3 мкс, ош. УОЗ ≤0.03° (средн. -0.01°); зубьев без синхр. 0/1120; катушка под током ≤1.60 мс, форсунка открыта ≤2.17 мс; метки времени зубьев: неверных 0 из 1287
[PASS] 6000 об/мин, 300 нс/обращение NEW: искр 640, пропущено 0, лишних 0; впрысков 640, пропущено 0; ош. впрыска ≤9.0 мкс, ош. накопления ≤11.6 мкс, ош. УОЗ ≤0.46° (средн. -0.09°); зубьев без синхр. 0/11200; катушка под током ≤1.60 мс, форсунка открыта ≤2.23 мс; метки времени зубьев: неверных 0 из 12942
[PASS] 7000 об/мин, 300 нс/обращение NEW: искр 747, пропущено 0, лишних 0; впрысков 746, пропущено 0; ош. впрыска ≤9.1 мкс, ош. накопления ≤11.7 мкс, ош. УОЗ ≤0.95° (средн. -0.33°); зубьев без синхр. 0/13067; катушка под током ≤1.61 мс, форсунка открыта ≤2.23 мс; метки времени зубьев: неверных 0 из 15101
[PASS] случайная цена обращения 50…150 нс, 12 прогонов (1100 и 6000 об/мин) NEW: пропущено искр 0, впрысков 0; ош. впрыска ≤3.6 мкс, ош. накопления ≤4.4 мкс, ош. УОЗ ≤0.20°

== Шкала времени micros(): фронты венца точно около переполнения 16-битного счётчика ==
[PASS] 500 фронтов в окне ±3 мкс от переполнения (шаг 25 нс) NEW: проверено меток 500, неверных 0, наибольшая задержка метки 3 мкс, переполнений 503
[info] то же OLD: проверено меток 1, неверных 1 (у v0.8 метка 16-разрядная, после первого переполнения она не равна времени)

== (д) Связь: 115200 бод, телеметрия 10 Гц включена ==
[PASS] залп 234 команд SET (3940 байт) в USART1 NEW: применено 234/234, ответов OK 234, GET CRC совпал (CRC,50329,36160,22772), основной цикл не задерживался дольше 0.33 мс
[info] тот же залп OLD: применено 234/234, ответов OK 234, основной цикл стоял до 18.4 мс
[PASS] залп 234 команд SET (3940 байт) в USART2/HC-06 NEW: применено 234/234, ответов OK 234, GET CRC совпал (CRC,50329,36160,22772), основной цикл не задерживался дольше 0.33 мс
[info] тот же залп OLD: применено 234/234, ответов OK 234, основной цикл стоял до 18.4 мс
[PASS] GET MAPS и сразу залп 234 команд SET NEW: применено 234/234, основной цикл ≤1.49 мс
[info] GET MAPS и сразу залп OLD: применено 170/234 (потеряно 64), основной цикл стоял до 114.7 мс
[PASS] 4×GET MAPS, 2×GET PARAMS, STATUS, INFO, PING подряд на работающем двигателе NEW: USART1: 128/128 строк ответов целы, телеметрии 26, повреждённых строк 0; USART2: 64/64, телеметрии 28, повреждённых 0; основной цикл ≤106.4 мс; двигатель 3000 об/мин: пропущено искр 0, впрысков 0
[info] то же OLD: USART1: 128/128 строк ответов целы, телеметрии 23, повреждённых строк 0; USART2: 64/64, телеметрии 22, повреждённых 0; основной цикл ≤770.0 мс; двигатель 3000 об/мин: пропущено искр 181, впрысков 109

== (д) Команды TEST и блокировки ==
[PASS] протокол: ответы на 40 команд (блокировка SERVICE, тесты, ошибки, блокировка при вращении) NEW: 48 строк совпали с эталоном
[info] сравнение с OLD: первые 39 строк идентичны (кроме номера версии); дальше отличия только из-за ошибок v0.8: при вращении 600 об/мин OLD ответил ["OK,TEST,COIL1","OK","OK,SAVED","TEST,DONE,COIL1"] — блокировка не сработала, потому что v0.8 ложно считает двигатель остановленным
[PASS] длительности тестовых импульсов NEW: форсунка 3001 мкс, катушка 1 1001 мкс, катушка 2 1001 мкс, РХХ 79/80 переключений фаз, насос 1999 мс, нагреватель 100 мс из 500
[info] длительности OLD: форсунка 3001 мкс, катушка 1 1001 мкс, катушка 2 1001 мкс, РХХ 79/80 переключений фаз, насос 1999 мс, нагреватель 98 мс из 500
[PASS] TEST COIL1 / TEST INJECTOR и сразу SAVE (запись Flash ~43 мс с запретом прерываний) NEW: катушка под током 427 мкс, форсунка открыта 430 мкс (импульс обрывается перед записью)
[info] то же OLD: катушка 1001 мкс, форсунка открыта 68537 мкс
[PASS] сторожевой таймер NEW: запущен, период 1002 мс, сбросов 0, наибольший интервал между обслуживаниями 43.0 мс (во время SAVE)

== Совместимость страницы калибровок 0x08007C00 ==
[PASS] образ Flash после SAVE у v0.8 и v0.9 побайтно одинаков: 1024 байта совпали
[PASS] v0.9 читает калибровки, сохранённые v0.8: BOOT …,FLASH; изменённые ячейки и параметры на месте
[PASS] v0.8 читает калибровки, сохранённые v0.9 (откат): BOOT …,FLASH; изменённые ячейки и параметры на месте

== Фильтр периода зуба (целочисленная арифметика, отдельный расчёт) ==
[PASS] после торможения период сходится к истинному NEW: истинный 278 мкс, фильтр v0.9 даёт 277.50 мкс
[info] OLD: фильтр v0.8 застревает на 271 мкс (−7 мкс = 2.5 %), т. е. искра раньше на ≈3.6° при 6000 об/мин

ИТОГ: проверок 48, не прошло 0 — PASS

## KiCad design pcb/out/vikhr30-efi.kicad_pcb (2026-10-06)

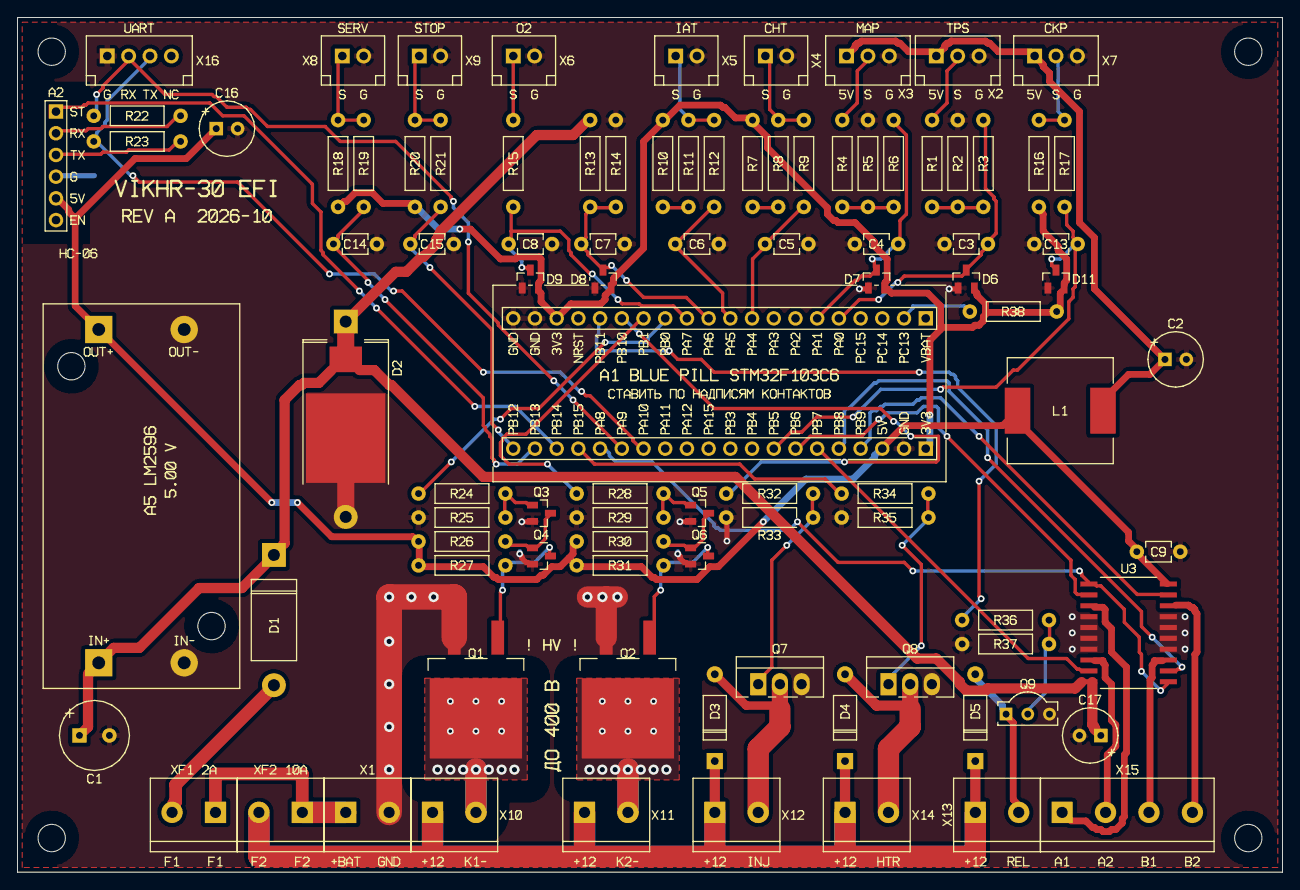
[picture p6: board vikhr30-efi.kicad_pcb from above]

Board: 2 copper layers, 148.0 x 100.0 mm, 98 parts (0 on the bottom side), 63 nets.

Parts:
A1: Blue Pill STM32F103C6T6; BLUEPILL_2x20
A2: HC-06; HDR_1x6
A5: LM2596S, 5,00 В; LM2596_MODULE
C1: 470 мкФ × 25 В; CP_D8_P3.5
C2, C16, C17: 47 мкФ × 63 В; CP_D6.3_P2.5
C3, C4, C5, C6, C7, C8, C9: 0,1 мкФ; C_DISC_5.08
C13, C14, C15: 1 нФ; C_DISC_5.08
D1: SR560; DO-201AD_15.24
D2: SM8S30A; DO-218AB
D3, D4, D5: 1N4007; DO-41_10.16
D6, D7, D8, D9, D11: BAR43S; SOT-23
H1, H2, H3, H4: M3; MountingHole_3.2mm_M3
L1: 47 мкГн; CDRH125
Q1, Q2: IRGS14C40L; TO-263-2
Q3, Q4, Q5, Q6: AO3400A; SOT-23
Q7, Q8: IRLZ44N; TO-220_V
Q9: BC547C; TO-92
R1, R4, R14, R15, R18, R20, R25, R29, R37, R38: 10 кОм; R_AXIAL_10.16
R2, R5: 20 кОм; R_AXIAL_10.16
R3, R6, R9, R12, R17, R19, R21, R22, R23, R26, R30, R36: 1 кОм; R_AXIAL_10.16
R7, R10: 2,4 кОм; R_AXIAL_10.16
R8, R11: 91 Ом; R_AXIAL_10.16
R13: 47 кОм; R_AXIAL_10.16
R16: 4,7 кОм; R_AXIAL_10.16
R24, R28: 330 Ом; R_AXIAL_10.16
R27, R31: 470 Ом; R_AXIAL_10.16
R32, R34: 100 Ом; R_AXIAL_10.16
R33, R35: 100 кОм; R_AXIAL_10.16
U3: L293DD; SO-20W
X1, X10, X11, X12, X13, X14: Клеммник 2 конт.; TERM_5.08_2
X2, X3, X7: JST XH 3 конт.; JST_XH_3
X4, X5, X6, X8, X9: JST XH 2 конт.; JST_XH_2
X15: JST XH 4 конт.; TERM_5.08_4
X16: JST XH 4 конт. (USB-UART A3); JST_XH_4
XF1: Клеммник 2 конт. к держателю F1 (2 А); TERM_5.08_2R
XF2: Клеммник 2 конт. к держателю F2 (10 А); TERM_5.08_2R

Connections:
+3V3: A1.JL18, A1.JR1, D6.2, D7.2, D8.2, D9.2, D11.2, R7.1, R10.1, R16.1, R18.1, R20.1, R38.1
+5V_ECU: A1.JR3, A2.5, A5.3, C9.1, C16.1, L1.1, R26.1, R27.1, R30.1, R31.1, U3.20
+5V_SENS: C2.1, L1.2, X2.1, X3.1, X7.1
+12V_F2: D3.1, D4.1, D5.1, X10.1, X11.1, X12.1, X13.1, X14.1, XF2.2
+12V_PROT: A5.1, C1.1, C17.1, D1.1, D2.1, R13.1, U3.10
BAT+: X1.1, XF1.1, XF2.1
COIL1-: Q1.2, X10.2
COIL2-: Q2.2, X11.2
GND: A1.JL19, A1.JL20, A1.JR2, A2.4, A5.2, A5.4, C1.2, C2.2, C3.2, C4.2, C5.2, C6.2, C7.2, C8.2, C9.2, C13.2, C14.2, C15.2, C16.2, C17.2, D2.2, D6.1, D7.1, D8.1, D9.1, D11.1, Q1.3, Q2.3, Q3.2, Q4.2, Q5.2, Q6.2, Q7.3, Q8.3, Q9.3, R2.2, R5.2, R14.2, R25.2, R29.2, R33.2, R35.2, R37.2, U3.4, U3.5, U3.6, U3.7, U3.14, U3.15, U3.16, U3.17, X1.2, X2.3, X3.3, X4.2, X5.2, X6.2, X7.3, X8.2, X9.2, X16.1
HEATER-: D4.2, Q8.2, X14.2
IAC_A1: U3.3, X15.1
IAC_A2: U3.8, X15.2
IAC_B1: U3.13, X15.3
IAC_B2: U3.18, X15.4
IGN1_GATE: Q1.1, Q4.3, R27.2
IGN2_GATE: Q2.1, Q6.3, R31.2
INJ-: D3.2, Q7.2, X12.2
MAP_SIG: R4.1, X3.2
N_D1_A: D1.2, XF1.2
N_Q3_1: Q3.1, R24.2, R25.1
N_Q3_3: Q3.3, Q4.1, R26.2
N_Q5_1: Q5.1, R28.2, R29.1
N_Q5_3: Q5.3, Q6.1, R30.2
N_Q7_1: Q7.1, R32.2, R33.1
N_Q8_1: Q8.1, R34.2, R35.1
N_Q9_2: Q9.2, R36.2, R37.1
N_R1_2: R1.2, R2.1, R3.1
N_R4_2: R4.2, R5.1, R6.1
N_R7_2: R7.2, R8.1
N_R10_2: R10.2, R11.1
PA0: A1.JL5, C3.1, D6.3, R3.2
PA1: A1.JL6, C4.1, D7.3, R6.2
PA4: A1.JL9, C5.1, R9.2
PA4_X4: R8.2, R9.1, X4.1
PA5: A1.JL10, C6.1, R12.2
PA5_X5: R11.2, R12.1, X5.1
PA6: A1.JL11, C7.1, D8.3, R13.2, R14.1
PA7: A1.JL12, C8.1, D9.3, R15.2
PA7_X6: R15.1, X6.1
PA8: A1.JR16, U3.1, U3.11
PA9: A1.JR15, R22.1, X16.2
PA9_A2: A2.2, R22.2
PA10: A1.JR14, R23.1, X16.3
PA10_A2: A2.3, R23.2
PB0: A1.JL13, R24.1
PB1: A1.JL14, R28.1
PB5: A1.JR8, C13.1, D11.3, R17.2
PB5_X7: R16.2, R17.1, X7.2
PB6: A1.JR7, U3.2
PB7: A1.JR6, U3.9
PB8: A1.JR5, U3.12
PB9: A1.JR4, U3.19
PB10: A1.JL15, R32.1
PB11: A1.JL16, R36.1
PB12: A1.JR20, C15.1, R21.2
PB12_X9: R20.2, R21.1, X9.1
PB13: A1.JR19, C14.1, R19.2
PB13_X8: R18.2, R19.1, X8.1
PB14: A1.JR18, A2.1
PB15: A1.JR17, R34.1
PC13: A1.JL2, R38.2
RELAY-: D5.2, Q9.1, X13.2
TPS_SIG: R1.1, X2.2

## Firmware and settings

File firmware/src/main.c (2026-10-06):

/*
 * Vikhr-30 EFI ECU v0.9.0 BT/UART + diagnostics + actuator test
 * STM32F103C6T6A, bare metal register-level firmware.
 * No Arduino Core, HAL, RTOS, dynamic allocation, or C runtime dependency.
 *
 * Trigger: Hall 36-1, first rising edge after the gap = 170 deg BTDC cyl. 1.
 * Fuel: one Bosch 0 280 158 117, 540 cc/min at 3 bar, two pulses/revolution.
 * Ignition: two Delphi 28198992 coils via two ST VBG08H-E drivers.
 * Idle: Continental 26179 bipolar stepper via DRV8843.
 * Tuning: USART1 service/HC-06 + USART2 fallback, 115200 8N1.
 * Native USB is deliberately disabled in this recovery build.
 *
 * v0.9 timing model (see README_RU.md):
 *  - TIM2 on the STM32F103 is a 16-bit counter.  It runs at 1 MHz and wraps
 *    every 65.536 ms; the update interrupt extends it to 32 bits (micros()).
 *  - EXTI9_5 (crank tooth) and TIM2 share ONE preemption priority, so they
 *    never interrupt each other.  All scheduler state (ev_time[], ev_pending,
 *    TIM2->DIER/CCR1, tim2_high) is touched only from those two handlers or
 *    from the main loop with interrupts masked.
 *  - Every output is switched on together with storing its switch-off event
 *    (same interrupt handler or critical section), so coil and injector
 *    on-times are bounded by the timer interrupt alone and do not depend on
 *    the main loop.
 *  - UART transmission is interrupt driven through ring buffers.
 */

#include "stm32f103xb_min.h"

#define FW_VERSION "0.9.0-C6-BT-DIAG"
#define ARRAY_LEN(a) ((uint32_t)(sizeof(a) / sizeof((a)[0])))

enum {
  RPM_COUNT = 13,
  LOAD_COUNT = 9,
  RX_SIZE = 512,          /* power of two */
  TX_SIZE = 2048,         /* power of two; holds a complete GET MAPS reply */
  LINE_SIZE = 192,
  STATUS_LINE_MAX = 256   /* upper bound of one "T,..." telemetry line */
};

/* Bounded busy-wait.  `ok` becomes 0 only if `cond` is still true after
   `limit` polls (v0.8 tested the wrapped counter and never saw a timeout). */
#define WAIT_WHILE(cond, limit, ok) \
  do { \
    uint32_t wait_left_ = (limit); \
    (ok) = 1; \
    while (cond) { if (--wait_left_ == 0U) { (ok) = 0; break; } } \
  } while (0)

static const uint16_t rpm_bins[RPM_COUNT] =
    {600, 900, 1200, 1600, 2200, 3000, 3800, 4500, 5000, 5500, 6000, 7000, 8000};
static const uint16_t load_bins[LOAD_COUNT] = {0, 20, 50, 100, 200, 350, 550, 750, 1000};

static const uint16_t default_fuel[LOAD_COUNT][RPM_COUNT] = {
  {1880,1590,1470,1260, 890, 770, 770, 770, 770, 770, 770, 770, 770},
  {1930,1670,1550,1410,1160,1060,1050,1030,1020,1020,1000, 990, 960},
  {2000,1790,1670,1620,1560,1500,1470,1420,1400,1380,1350,1310,1250},
  {2150,2000,1910,1850,1820,1770,1750,1730,1710,1700,1670,1640,1590},
  {2410,2280,2200,2150,2130,2120,2120,2110,2090,2070,2050,2020,1970},
  {2650,2560,2500,2480,2480,2480,2500,2500,2490,2460,2430,2400,2340},
  {2950,2870,2840,2830,2850,2890,2920,2940,2920,2870,2840,2810,2750},
  {3190,3140,3120,3110,3150,3200,3240,3250,3240,3190,3160,3140,3070},
  {3420,3380,3360,3370,3410,3440,3470,3450,3410,3320,3300,3250,3180}
};

/* Degrees BTDC multiplied by ten. */
static const int16_t default_ign[LOAD_COUNT][RPM_COUNT] = {
  {50,100,140,180,220,260,280,280,270,250,240,220,200},
  {50,100,140,180,224,264,284,284,274,254,240,220,200},
  {50,100,140,180,230,270,290,290,280,260,240,220,200},
  {50, 90,130,180,230,270,290,290,280,260,240,220,200},
  {50, 90,130,170,220,260,280,280,270,250,230,210,190},
  {50, 80,120,170,210,250,270,270,260,240,220,200,180},
  {50, 80,120,160,208,248,268,268,258,238,218,188,168},
  {50, 80,120,160,200,240,260,260,250,230,210,180,160},
  {50, 80,120,160,200,240,260,260,250,230,210,180,160}
};

enum FaultBits {
  FAULT_EVENT_OVERFLOW = 1U << 0,
  FAULT_DWELL_SHORT     = 1U << 1,
  FAULT_PW_CLAMP        = 1U << 2,
  FAULT_SENSOR          = 1U << 3,
  FAULT_OVERHEAT        = 1U << 4,
  FAULT_REV_LIMIT       = 1U << 5,
  FAULT_SYNC_LOSS       = 1U << 6,
  FAULT_IAC_DRIVER      = 1U << 7,
  FAULT_O2_INVALID      = 1U << 8,
  FAULT_FLASH           = 1U << 9
};

typedef struct {
  uint32_t magic;
  uint16_t version;
  uint16_t size;
  uint16_t fuel_us[LOAD_COUNT][RPM_COUNT];
  int16_t ignition_tenths[LOAD_COUNT][RPM_COUNT];
  int16_t trigger_trim_tenths;
  uint16_t dwell_us;
  uint16_t injector_deadtime_us;
  uint16_t tps_min_raw;
  uint16_t tps_max_raw;
  uint16_t fuel_scale_permille;
  uint16_t soft_rev_limit;
  uint16_t hard_rev_limit;
  uint16_t iac_max_steps;
  uint16_t iac_crank_steps;
  uint16_t iac_hot_steps;
  uint16_t iac_target_rpm;
  int8_t iac_direction;
  uint8_t o2_heater_duty_pct;
  uint8_t o2_mode; /* 0: OSM28488580 narrowband, 1: external 0-5 V wideband */
  uint8_t reserved;
  uint16_t wideband_lambda_min_milli;
  uint16_t wideband_lambda_max_milli;
  uint16_t crc;
} Calibration;

/* The Flash image of this structure is shared with v0.8: layout is frozen. */
_Static_assert(sizeof(Calibration) == 512, "calibration layout changed");
_Static_assert(__builtin_offsetof(Calibration, fuel_us) == 8, "calibration layout changed");
_Static_assert(__builtin_offsetof(Calibration, ignition_tenths) == 242, "calibration layout changed");
_Static_assert(__builtin_offsetof(Calibration, trigger_trim_tenths) == 476, "calibration layout changed");
_Static_assert(__builtin_offsetof(Calibration, crc) == 508, "calibration layout changed");

#define CAL_MAGIC 0x56454649UL
#define CAL_VERSION 5U
#define CAL_FLASH_ADDRESS 0x08007C00UL

static Calibration cal;
static volatile uint32_t ms_ticks;
static uint32_t core_clock_hz = 8000000U;
static uint32_t apb1_clock_hz = 8000000U;
static uint8_t clock_pll_ok;
static volatile uint16_t fault_flags;
static volatile uint16_t engine_rpm;
static volatile uint8_t crank_synced;
static volatile uint32_t last_crank_edge_us;
static volatile uint8_t crank_recent; /* a valid tooth was seen within the last second */
static volatile uint16_t prepared_fuel_us = 1600;
static volatile uint16_t prepared_dwell_us = 1600;
static volatile int16_t prepared_advance_tenths = 50;
static volatile int16_t prepared_trigger_tenths = 1700;
static volatile uint8_t prepared_fuel_cut;
static int16_t fixed_ign_tenths = -1;
static uint16_t peak_rpm;
static uint16_t current_fuel_us;
static int16_t current_advance_tenths;

typedef struct {
  uint16_t tps_raw;
  uint16_t tps_tenths;
  uint16_t map_kpa_tenths;
  int16_t cht_c_tenths;
  int16_t iat_c_tenths;
  uint16_t battery_mv;
  uint16_t o2_mv;
  uint16_t lambda_milli;
  int8_t lambda_direction; /* -1 rich, 0 target/transition, +1 lean, +2 warming/invalid */
  uint16_t baro_kpa_tenths;
} SensorState;

static SensorState sensors = {0, 0, 1013, 200, 200, 12500, 450, 0, 2, 1013};
static uint16_t accel_enrich_permille = 1000;
static uint16_t previous_tps_tenths;
static uint32_t last_sensor_ms;

typedef struct {
  USART_TypeDef *hw;
  volatile uint16_t head, tail;       /* RX ring: ISR writes head, main writes tail */
  volatile uint16_t tx_head, tx_tail; /* TX ring: main writes head, ISR writes tail */
  uint16_t line_len;
  char rx[RX_SIZE];
  char tx[TX_SIZE];
  char line[LINE_SIZE];
} SerialPort;

/* Zero-initialised (.bss); the hw pointers are set in uart_init(). */
static SerialPort wire_port;
static SerialPort bt_port;
static uint8_t stream_hz = 10;
static uint32_t last_stream_ms;

enum ActuatorTest {
  ACT_TEST_NONE = 0,
  ACT_TEST_PUMP,
  ACT_TEST_INJECTOR,
  ACT_TEST_COIL1,
  ACT_TEST_COIL2,
  ACT_TEST_IAC_OPEN,
  ACT_TEST_IAC_CLOSE,
  ACT_TEST_O2_HEATER
};
static volatile uint8_t actuator_test;
static uint32_t actuator_test_deadline_ms, actuator_test_next_ms;
static uint16_t actuator_test_steps;

static uint8_t str_eq(const char *a, const char *b);
static uint8_t mutation_allowed(void);

static void mem_zero(void *target, uint32_t length) {
  uint8_t *p = (uint8_t *)target;
  while (length--) *p++ = 0;
}

static void mem_copy(void *target, const void *source, uint32_t length) {
  uint8_t *d = (uint8_t *)target;
  const uint8_t *s = (const uint8_t *)source;
  while (length--) *d++ = *s++;
}

/* fault_flags is modified by the main loop and by the tooth interrupt. */
static void fault_set(uint16_t bits) {
  uint32_t primask = irq_save();
  fault_flags |= bits;
  irq_restore(primask);
}

static void fault_clear(uint16_t bits) {
  uint32_t primask = irq_save();
  fault_flags &= (uint16_t)~bits;
  irq_restore(primask);
}

static int32_t clamp_i32(int32_t v, int32_t lo, int32_t hi) {
  return v < lo ? lo : (v > hi ? hi : v);
}

static uint16_t crc16_ccitt(const uint8_t *data, uint32_t length) {
  uint16_t crc = 0xFFFFU;
  while (length--) {
    crc ^= (uint16_t)(*data++) << 8;
    for (uint8_t i = 0; i < 8; ++i)
      crc = (crc & 0x8000U) ? (uint16_t)((crc << 1) ^ 0x1021U)
                            : (uint16_t)(crc << 1);
  }
  return crc;
}

static uint32_t calibration_crc_length(void) {
  return (uint32_t)((uintptr_t)&cal.crc - (uintptr_t)&cal);
}

static void load_defaults(void) {
  mem_zero(&cal, sizeof(cal));
  cal.magic = CAL_MAGIC;
  cal.version = CAL_VERSION;
  cal.size = (uint16_t)sizeof(cal);
  mem_copy(cal.fuel_us, default_fuel, sizeof(default_fuel));
  mem_copy(cal.ignition_tenths, default_ign, sizeof(default_ign));
  cal.dwell_us = 1600;
  cal.injector_deadtime_us = 650;
  cal.tps_min_raw = 420;
  cal.tps_max_raw = 3720;
  cal.fuel_scale_permille = 1000;
  cal.soft_rev_limit = 6800;
  cal.hard_rev_limit = 7000;
  cal.iac_max_steps = 180;
  cal.iac_crank_steps = 90;
  cal.iac_hot_steps = 30;
  cal.iac_target_rpm = 1100;
  cal.iac_direction = 1;
  cal.o2_heater_duty_pct = 70;
  cal.o2_mode = 0;
  cal.wideband_lambda_min_milli = 700;
  cal.wideband_lambda_max_milli = 1300;
  cal.crc = crc16_ccitt((const uint8_t *)&cal, calibration_crc_length());
}

static uint8_t load_calibration(void) {
  const Calibration *stored = (const Calibration *)CAL_FLASH_ADDRESS;
  mem_copy(&cal, stored, sizeof(cal));
  uint16_t expected = crc16_ccitt((const uint8_t *)&cal, calibration_crc_length());
  if (cal.magic != CAL_MAGIC || cal.version != CAL_VERSION ||
      cal.size != sizeof(cal) || cal.crc != expected) {
    load_defaults();
    return 0;
  }
  cal.reserved = 0; /* always zero in RAM so that GET CRC is reproducible */
  return 1;
}

static uint8_t flash_wait(void) {
  uint8_t ok;
  WAIT_WHILE(FLASH_IF->SR & FLASH_SR_BSY, 3000000U, ok);
  if (!ok || (FLASH_IF->SR & (FLASH_SR_PGERR | FLASH_SR_WRPRTERR))) return 0;
  return 1;
}

static uint8_t save_calibration(void) {
  cal.magic = CAL_MAGIC;
  cal.version = CAL_VERSION;
  cal.size = (uint16_t)sizeof(cal);
  cal.crc = crc16_ccitt((const uint8_t *)&cal, calibration_crc_length());
  irq_disable();
  if (FLASH_IF->CR & FLASH_CR_LOCK) {
    FLASH_IF->KEYR = 0x45670123UL;
    FLASH_IF->KEYR = 0xCDEF89ABUL;
  }
  FLASH_IF->SR = FLASH_SR_EOP | FLASH_SR_PGERR | FLASH_SR_WRPRTERR;
  FLASH_IF->CR |= FLASH_CR_PER;
  FLASH_IF->AR = CAL_FLASH_ADDRESS;
  FLASH_IF->CR |= FLASH_CR_STRT;
  uint8_t ok = flash_wait();
  FLASH_IF->CR &= ~FLASH_CR_PER;
  const uint16_t *source = (const uint16_t *)&cal;
  volatile uint16_t *target = (volatile uint16_t *)CAL_FLASH_ADDRESS;
  if (ok) {
    FLASH_IF->CR |= FLASH_CR_PG;
    for (uint32_t i = 0; i < (sizeof(cal) + 1U) / 2U; ++i) {
      target[i] = source[i];
      if (!flash_wait()) { ok = 0; break; }
    }
    FLASH_IF->CR &= ~FLASH_CR_PG;
  }
  FLASH_IF->CR |= FLASH_CR_LOCK;
  irq_enable();
  if (!ok) fault_set(FAULT_FLASH);
  return ok;
}

static void gpio_config(GPIO_TypeDef *port, uint8_t pin, uint8_t nibble) {
  volatile uint32_t *cr = pin < 8 ? &port->CRL : &port->CRH;
  uint8_t shift = (uint8_t)((pin & 7U) * 4U);
  *cr = (*cr & ~(0xFUL << shift)) | ((uint32_t)nibble << shift);
}

static void gpio_write(GPIO_TypeDef *port, uint8_t pin, uint8_t high) {
  port->BSRR = high ? (1UL << pin) : (1UL << (pin + 16U));
}

static uint8_t gpio_read(GPIO_TypeDef *port, uint8_t pin) {
  return (port->IDR & (1UL << pin)) != 0;
}

static uint8_t kill_active(void) { return !gpio_read(GPIOB, 12); }
static uint8_t service_jumper(void) { return !gpio_read(GPIOB, 13); }
static uint8_t bluetooth_connected(void) { return gpio_read(GPIOB, 14); }

static void clock_init(void) {
  /*
   * Use the internal 8 MHz oscillator as the only clock source.  This removes
   * the hard dependency on the clone board's HSE crystal and its load parts.
   * HSI/2 * 16 = 64 MHz; APB1 is divided by two and the ADC by six.
   */
  uint8_t ok;
  RCC->CR |= 1UL << 0; /* HSION */
  WAIT_WHILE(!(RCC->CR & (1UL << 1)), 2000000U, ok);

  RCC->CFGR &= ~3UL; /* request HSI before reconfiguring PLL */
  WAIT_WHILE(((RCC->CFGR >> 2) & 3UL) != 0U, 2000000U, ok);
  RCC->CR &= ~(1UL << 24); /* PLL off */
  WAIT_WHILE(RCC->CR & (1UL << 25), 2000000U, ok);

  FLASH_IF->ACR = FLASH_ACR_PRFTBE | FLASH_ACR_LATENCY_2;
  RCC->CFGR = (4UL << 8) | (2UL << 14) | (14UL << 18);
  RCC->CR |= 1UL << 24; /* PLLON */
  WAIT_WHILE(!(RCC->CR & (1UL << 25)), 2000000U, ok);
  if (ok) {
    RCC->CFGR = (RCC->CFGR & ~3UL) | 2UL;
    WAIT_WHILE(((RCC->CFGR >> 2) & 3UL) != 2UL, 2000000U, ok);
    if (ok) {
      core_clock_hz = 64000000U;
      apb1_clock_hz = 32000000U;
      clock_pll_ok = 1U;
      return;
    }
  }

  /* Safe fallback: direct HSI at 8 MHz.  No wait below can block forever. */
  RCC->CFGR &= ~3UL;
  WAIT_WHILE(((RCC->CFGR >> 2) & 3UL) != 0U, 2000000U, ok);
  RCC->CR &= ~(1UL << 24);
  RCC->CFGR = 0U;
  FLASH_IF->ACR = FLASH_ACR_PRFTBE;
  core_clock_hz = 8000000U;
  apb1_clock_hz = 8000000U;
  clock_pll_ok = 0U;
  (void)ok;
}

static void systick_init(void) {
  SYST_RVR = core_clock_hz / 1000U - 1U;
  SYST_CVR = 0;
  SYST_CSR = 7U;
}

static void watchdog_init(void) {
  /*
   * LSI nominal 40 kHz: prescaler 64 and reload 625 give about 1 s.
   * The watchdog is started first: that forces the LSI oscillator on, and
   * PR/RLR are only transferred (IWDG->SR returns to 0) while the LSI runs.
   * If the transfer times out the watchdog still runs with its reset
   * defaults (about 0.4 s), which the main loop also satisfies.
   */
  uint8_t ok;
  IWDG->KR = 0xCCCCU;
  IWDG->KR = 0x5555U;
  IWDG->PR = 4U;
  IWDG->RLR = 625U;
  WAIT_WHILE(IWDG->SR, 500000U, ok);
  IWDG->KR = 0xAAAAU;
  if (!ok) fault_set(FAULT_SENSOR);
}

void SysTick_Handler(void) { ++ms_ticks; }

static void uart_init(void) {
  /* PA9/PA2 AF push-pull; PA10/PA3 floating input. */
  wire_port.hw = USART1;
  bt_port.hw = USART2;
  gpio_config(GPIOA, 9, 0xA); gpio_config(GPIOA, 10, 0x4);
  gpio_config(GPIOA, 2, 0xA); gpio_config(GPIOA, 3, 0x4);
  USART1->BRR = (core_clock_hz + 57600U) / 115200U;
  USART2->BRR = (apb1_clock_hz + 57600U) / 115200U;
  USART1->CR1 = USART_CR1_UE | USART_CR1_RE | USART_CR1_TE | USART_CR1_RXNEIE;
  USART2->CR1 = USART_CR1_UE | USART_CR1_RE | USART_CR1_TE | USART_CR1_RXNEIE;
  NVIC_IPR[37] = 0x60; NVIC_IPR[38] = 0x60;
  NVIC_ISER1 = (1UL << (37 - 32)) | (1UL << (38 - 32));
}

static void serial_isr(SerialPort *port) {
  USART_TypeDef *hw = port->hw;
  uint32_t sr = hw->SR;
  /* Reading DR after SR also clears an overrun; otherwise ORE without RXNE
     would re-enter this handler forever. */
  if (sr & (USART_SR_RXNE | USART_SR_ORE)) {
    char ch = (char)hw->DR;
    if (sr & USART_SR_RXNE) {
      uint16_t head = port->head;
      uint16_t next = (uint16_t)((head + 1U) & (RX_SIZE - 1U));
      if (next != port->tail) { port->rx[head] = ch; port->head = next; }
    }
  }
  if ((sr & USART_SR_TXE) && (hw->CR1 & USART_CR1_TXEIE)) {
    uint16_t tail = port->tx_tail;
    if (tail != port->tx_head) {
      hw->DR = (uint8_t)port->tx[tail];
      port->tx_tail = (uint16_t)((tail + 1U) & (TX_SIZE - 1U));
    } else {
      hw->CR1 &= ~USART_CR1_TXEIE; /* ring empty: stop TXE interrupts */
    }
  }
}

void USART1_IRQHandler(void) { serial_isr(&wire_port); }
void USART2_IRQHandler(void) { serial_isr(&bt_port); }

static uint16_t port_tx_free(const SerialPort *port) {
  return (uint16_t)((port->tx_tail - port->tx_head - 1U) & (TX_SIZE - 1U));
}

/*
 * Queue one character.  Never waits while there is room.  If the ring is
 * full (a long reply such as GET MAPS) it waits for the TXE interrupt to
 * free a slot, so command replies are not lost; telemetry avoids this path
 * by checking port_tx_free() first.  Must be called from the main loop only,
 * with interrupts enabled.
 */
static void port_char(SerialPort *port, char ch) {
  uint16_t head = port->tx_head;
  uint16_t next = (uint16_t)((head + 1U) & (TX_SIZE - 1U));
  uint8_t ok;
  WAIT_WHILE(next == port->tx_tail, 400000U, ok);
  if (!ok) return; /* transmitter stuck: drop the character, never hang */
  port->tx[head] = ch;
  port->tx_head = next;
  uint32_t primask = irq_save();
  port->hw->CR1 |= USART_CR1_TXEIE;
  irq_restore(primask);
}

static void port_text(SerialPort *port, const char *text) {
  while (*text) port_char(port, *text++);
}

static void port_u32(SerialPort *port, uint32_t value) {
  char digits[11]; uint8_t n = 0;
  do { digits[n++] = (char)('0' + value % 10U); value /= 10U; } while (value);
  while (n) port_char(port, digits[--n]);
}

static void port_i32(SerialPort *port, int32_t value) {
  if (value < 0) { port_char(port, '-'); value = -value; }
  port_u32(port, (uint32_t)value);
}

static void port_csv_u32(SerialPort *port, uint32_t value) {
  port_char(port, ','); port_u32(port, value);
}

static void port_csv_i32(SerialPort *port, int32_t value) {
  port_char(port, ','); port_i32(port, value);
}

static void port_line(SerialPort *port, const char *text) {
  port_text(port, text); port_text(port, "\r\n");
}

static uint16_t adc_read(uint8_t channel) {
  ADC1->SQR3 = channel;
  ADC1->SR = 0;
  ADC1->CR2 |= 1UL << 22;
  uint8_t ok;
  WAIT_WHILE(!(ADC1->SR & (1UL << 1)), 100000U, ok);
  if (!ok) fault_set(FAULT_SENSOR);
  return (uint16_t)ADC1->DR;
}

static void adc_init(void) {
  ADC1->SMPR2 = 0x00DB6DB6UL; /* 71.5 cycles for channels 0..7 */
  ADC1->CR2 = (1UL << 20) | (7UL << 17) | 1UL;
  for (volatile uint32_t i = 0; i < 10000U; ++i) cpu_nop();
  uint8_t ok;
  ADC1->CR2 |= 1UL << 3;
  WAIT_WHILE(ADC1->CR2 & (1UL << 3), 500000U, ok);
  if (!ok) fault_set(FAULT_SENSOR);
  ADC1->CR2 |= 1UL << 2;
  WAIT_WHILE(ADC1->CR2 & (1UL << 2), 500000U, ok);
  if (!ok) fault_set(FAULT_SENSOR);
}

typedef struct { uint16_t adc; int16_t temp_tenths; } NtcPoint;
static const NtcPoint cht_table[] = {
  {4000,-200},{3927,-100},{3813,0},{3645,100},{3416,200},{3126,300},
  {2786,400},{2417,500},{2046,600},{1696,700},{1383,800},{1117,900},
  {896,1000},{718,1100},{575,1200},{463,1300},{374,1400}
};
static const NtcPoint iat_table[] = {
  {3558,-200},{3262,-100},{2893,0},{2477,100},{2052,200},{1653,300},
  {1306,400},{1019,500},{791,600},{614,700},{478,800},{374,900},
  {295,1000},{235,1100},{188,1200},{152,1300},{124,1400}
};

static int16_t ntc_lookup(uint16_t adc, const NtcPoint *table, uint32_t count) {
  if (adc >= table[0].adc) return table[0].temp_tenths;
  if (adc <= table[count - 1].adc) return table[count - 1].temp_tenths;
  for (uint32_t i = 0; i + 1U < count; ++i) {
    if (adc <= table[i].adc && adc >= table[i + 1U].adc) {
      int32_t span = (int32_t)table[i].adc - table[i + 1U].adc;
      int32_t offset = (int32_t)table[i].adc - adc;
      return (int16_t)(table[i].temp_tenths +
          offset * (table[i + 1U].temp_tenths - table[i].temp_tenths) / span);
    }
  }
  return 200;
}

static int32_t smooth_i32(int32_t old_value, int32_t new_value, uint8_t num, uint8_t den) {
  return old_value + (new_value - old_value) * num / den;
}

static volatile uint8_t current_o2_heater_pct;
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
int main(void) {
  hardware_init();
  uint8_t calibration_ok = load_calibration();
  iac_homing_remaining = cal.iac_max_steps + 40;
  for(uint8_t i=0;i<16;++i)read_sensors();
  sensors.baro_kpa_tenths=sensors.map_kpa_tenths;
  if(!kill_active())gpio_write(GPIOB,11,1);
  port_text(&wire_port,"BOOT,VIKHR30_STM32,");port_text(&wire_port,FW_VERSION);port_char(&wire_port,',');port_line(&wire_port,calibration_ok?"FLASH":"DEFAULTS");
  port_text(&bt_port,"BOOT,VIKHR30_STM32,");port_text(&bt_port,FW_VERSION);port_char(&bt_port,',');port_line(&bt_port,calibration_ok?"FLASH":"DEFAULTS");
  watchdog_init();
  for(;;){
    IWDG->KR=0xAAAAU;
    uint32_t now_ms=ms_ticks;
    service_port(&wire_port);service_port(&bt_port);
    if(now_ms-last_sensor_ms>=10U){last_sensor_ms=now_ms;read_sensors();prepare_realtime();}
    /* Engine-stopped detection.  Edge time, current time and the state
       change are handled in one critical section, so a tooth interrupt
       cannot slip in between (v0.8 sampled the timer before the edge). */
    uint32_t primask=irq_save();
    uint8_t recent=crank_recent,stopped=0;
    uint32_t age=micros()-last_crank_edge_us;
    if(recent&&age>=1000000U){crank_recent=0;recent=0;}
    uint16_t rpm=engine_rpm;uint8_t sync=crank_synced;
    if(recent&&age>250000U&&(sync||rpm)){
      crank_synced=0;engine_rpm=0;tooth_index=255;tooth_acc=0;tooth_seen=0;normal_run=0;
      rpm=0;sync=0;stopped=1;
    }
    irq_restore(primask);
    if(stopped){fault_set(FAULT_SYNC_LOSS);clear_events_outputs();}
    if(actuator_test!=ACT_TEST_IAC_OPEN&&actuator_test!=ACT_TEST_IAC_CLOSE)update_iac(now_ms,rpm);
    if(actuator_test!=ACT_TEST_O2_HEATER)update_o2_heater(now_ms,rpm,sync);
    if(kill_active()){
      if(actuator_test!=ACT_TEST_NONE)stop_actuator_test(1);
      gpio_write(GPIOB,11,0);clear_events_outputs();
    }
    else if(actuator_test==ACT_TEST_PUMP){}
    else if(now_ms<2000U||recent)gpio_write(GPIOB,11,1);
    else gpio_write(GPIOB,11,0);
    service_actuator_test(now_ms);
    if(stream_hz&&now_ms-last_stream_ms>=1000U/stream_hz){
      last_stream_ms=now_ms;
      /* Telemetry is never allowed to wait: a line is sent whole or skipped. */
      if(port_tx_free(&wire_port)>=STATUS_LINE_MAX)print_status(&wire_port);
      if(port_tx_free(&bt_port)>=STATUS_LINE_MAX)print_status(&bt_port);
    }
  }
}

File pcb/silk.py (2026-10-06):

# -*- coding: utf-8 -*-
"""Шелкография: контуры деталей (обрезанные у площадок), позиционные обозначения (авторазмещение), подписи контактов, надписи."""
import json, math, os
import numpy as np
import board as B, geom as G, font as F

LW = 0.15
TH = 1.0
SILK_PAD_GAP = 0.15

def load():
    return json.load(open(os.path.join(B.HERE, 'design.json')))

PIN_LABELS = {  # подписи контактов клеммников (у кромки платы) и разъёмов
    'XF1': {'1': 'F1', '2': 'F1'}, 'XF2': {'1': 'F2', '2': 'F2'}, 'X1': {'1': '+BAT', '2': 'GND'},
    'X10': {'1': '+12', '2': 'K1-'}, 'X11': {'1': '+12', '2': 'K2-'}, 'X12': {'1': '+12', '2': 'INJ'}, 'X14': {'1': '+12', '2': 'HTR'},
    'X13': {'1': '+12', '2': 'REL'}, 'X15': {'1': 'A1', '2': 'A2', '3': 'B1', '4': 'B2'},
    'X2': {'1': '5V', '2': 'S', '3': 'G'}, 'X3': {'1': '5V', '2': 'S', '3': 'G'}, 'X7': {'1': '5V', '2': 'S', '3': 'G'},
    'X4': {'1': 'S', '2': 'G'}, 'X5': {'1': 'S', '2': 'G'}, 'X6': {'1': 'S', '2': 'G'}, 'X8': {'1': 'S', '2': 'G'}, 'X9': {'1': 'S', '2': 'G'},
    'X16': {'1': 'G', '2': 'RX', '3': 'TX', '4': 'NC'},
    'A2': {'1': 'ST', '2': 'RX', '3': 'TX', '4': 'G', '5': '5V', '6': 'EN'},
    'A5': {'1': 'IN+', '2': 'IN-', '3': 'OUT+', '4': 'OUT-'},
}
CONN_NAME = {'X2': 'TPS', 'X3': 'MAP', 'X4': 'CHT', 'X5': 'IAT', 'X6': 'O2', 'X7': 'CKP', 'X8': 'SERV', 'X9': 'STOP', 'X16': 'UART'}
REF_TEXT = {'XF1': 'XF1 2A', 'XF2': 'XF2 10A'}
MCU = {**{f'JL{i + 1}': n for i, n in enumerate('VBAT PC13 PC14 PC15 PA0 PA1 PA2 PA3 PA4 PA5 PA6 PA7 PB0 PB1 PB10 PB11 NRST 3V3 GND GND'.split())},
       **{f'JR{i + 1}': n for i, n in enumerate('3V3 GND 5V PB9 PB8 PB7 PB6 PB5 PB4 PB3 PA15 PA12 PA11 PA10 PA9 PA8 PB15 PB14 PB13 PB12'.split())}}

def pad_shape(p, layer='T'):
    s = [q for q in B.shapes_of_pad(p) if q.layer == layer]
    return s[0] if s else None

def build(d):
    comps = d['comps']
    top_pads = []; bot_pads = []
    for c in comps:
        for p in c['pads']:
            if p['layers'] == 'T0': continue
            top_pads.append(pad_shape(p, 'T'))
            if p['layers'] == 'TB': bot_pads.append(pad_shape(p, 'B'))
    holes = [(x, y, dr) for c in comps for p in c['pads'] if p['drill'] for (x, y, dr) in [(p['x'], p['y'], p['drill'])]] + [(x, y, dd) for x, y, dd in d['npth']]
    via_holes = [(v[0], v[1], v[3]) for v in d['vias']]
    obst = {'T': top_pads + [G.Shape('T', None, [(x, y)], dr / 2) for x, y, dr in holes], 'B': bot_pads + [G.Shape('B', None, [(x, y)], dr / 2) for x, y, dr in holes]}
    vobst = [G.Shape('T', None, [(x, y)], dr / 2) for x, y, dr in via_holes]
    silk = {'T': [], 'B': []}
    texts = []      # (side, text, x, y, h, rot, bbox)
    report = {'via_overlaps': 0, 'fallback': []}

    def clip(seg, side, w=LW):
        """Обрезать отрезок у площадок/отверстий."""
        x1, y1, x2, y2 = seg
        L = math.hypot(x2 - x1, y2 - y1)
        if L < 1e-6: return []
        n = max(1, int(math.ceil(L / 0.05)))
        t = (np.arange(n) + 0.5) / n
        X = x1 + (x2 - x1) * t; Y = y1 + (y2 - y1) * t
        ok = np.ones(n, bool)
        bb = (min(x1, x2) - 2, min(y1, y2) - 2, max(x1, x2) + 2, max(y1, y2) + 2)
        for s in obst[side] + vobst:
            if s.bb[2] < bb[0] or s.bb[0] > bb[2] or s.bb[3] < bb[1] or s.bb[1] > bb[3]: continue
            ok &= G.dist_grid(s, X, Y) > SILK_PAD_GAP + B.MASK_EXP + w / 2 + 0.03
        ok &= (X > 0.4) & (X < d['W'] - 0.4) & (Y > 0.4) & (Y < d['H'] - 0.4)
        out = []; i = 0
        while i < n:
            if ok[i]:
                j = i
                while j + 1 < n and ok[j + 1]: j += 1
                a, b_ = i / n, (j + 1) / n
                if (b_ - a) * L >= 0.3: out.append((x1 + (x2 - x1) * a, y1 + (y2 - y1) * a, x1 + (x2 - x1) * b_, y1 + (y2 - y1) * b_, w))
                i = j + 1
            else: i += 1
        return out

    for c in comps:
        for sg in c['silk']: silk['T'] += clip(sg, 'T')

    placed = []     # bbox занятых надписями
    courts = {c['ref']: c['court'] for c in comps}
    def free(bb, side, own=None, check_courts=True, soft_vias=True):
        if bb[0] < 0.7 or bb[1] < 0.7 or bb[2] > d['W'] - 0.7 or bb[3] > d['H'] - 0.7: return False
        m = SILK_PAD_GAP + B.MASK_EXP + LW / 2 + 0.05
        for s in obst[side]:
            if s.bb[0] - m < bb[2] and bb[0] < s.bb[2] + m and s.bb[1] - m < bb[3] and bb[1] < s.bb[3] + m: return False
        if soft_vias:
            for s in vobst:
                if s.bb[0] - 0.1 < bb[2] and bb[0] < s.bb[2] + 0.1 and s.bb[1] - 0.1 < bb[3] and bb[1] < s.bb[3] + 0.1: return False
        for q in placed:
            if q[4] == side and q[0] - 0.5 < bb[2] and bb[0] < q[2] + 0.5 and q[1] - 0.25 < bb[3] and bb[1] < q[3] + 0.25: return False
        if check_courts:
            for r, ct in courts.items():
                if r == own: continue
                if ct[0] < bb[2] and bb[0] < ct[2] and ct[1] < bb[3] and bb[1] < ct[3]: return False
        return True
    def put(side, s, x, y, h=TH, rot=0, anchor='c', w=LW):
        bb = F.bbox(s, x, y, h, rot, anchor)
        placed.append((bb[0], bb[1], bb[2], bb[3], side))
        for sg in F.strokes(s, x, y, h, rot, anchor, mirror=(side == 'B')): silk[side].append((sg[0], sg[1], sg[2], sg[3], w))
        texts.append(dict(side=side, text=s, x=x, y=y, h=h, rot=rot, anchor=anchor, bbox=bb))
    def try_put(side, s, cands, own=None, h=TH, note=''):
        for relax in (0, 1, 2):
            for (x, y, rot, anchor, inside) in cands:
                bb = F.bbox(s, x, y, h, rot, anchor)
                if free(bb, side, own=own, check_courts=(not inside and relax < 1), soft_vias=(relax < 2)):
                    put(side, s, x, y, h, rot, anchor)
                    if relax: report['fallback'].append(f'{s}: {"поверх переходного (закрыто маской)" if relax == 2 else "в габарите соседней детали"}')
                    if relax == 2: report['via_overlaps'] += 1
                    return True
        report['fallback'].append(f'{s}: НЕ РАЗМЕЩЕНО {note}')
        return False
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
